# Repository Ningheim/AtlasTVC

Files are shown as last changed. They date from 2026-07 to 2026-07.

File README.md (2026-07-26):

# AtlasTVC
An easily edit-able TVC mount model for any rocketry hobbyist to use on their own rocket. From the clearance between gimbals, to the motor tube outder diameter that you'll be using with this design, everything here is easily adjustable via the variables seen inside the onshape document.

Atlas

Access the onshape document [here](https://cad.onshape.com/documents/687bb891e5fdc86e637405f0/w/7709ffe7004c15a579f76044/e/4d2dc5f323421dbaa3c98495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)
<br>
Printed model available on [Printables](https://www.printables.com/model/1791204-atlastvc)
<br>
*Note: I can't Commit the native CAD source file since the only option is to share via a link*

## Adjustments
Ok as you can see below, the variables control the form factor of the amount so you can adjust it to adhere to whatever you'd like:

<br>
Here's a brief description of each variable so you know exactly what each one represents
#### MotorTubeOD
Outer diameter of the motor tube the mount is built around
#### BaseThickness
This adjusts the thickness of the innermost gimbal, the specific part is called "Base Rig"
#### SecondaryThickness
This adjusts the thickness of the middle gimbal, the specific part is called "Secondary Rig"
#### TertiaryThickness
This adjusts the thickness of the outermost gimbal, the specific part is called "Tertiary Rig"
#### Clearance
Gap between the Base Rig and Secondary Rig axes so they can pivot freely without binding
#### Clearance2
Gap between the Secondary Rig and Tertiary Rig axes so they can pivot freely without binding
#### AxisSize
Diameter of the pivot axis pins connecting each gimbal ring
#### Servo1Offset
Mounting offset for the first servo. The servo head/servo horn needs to be tangent in a way to the cylindrical part it's going to be pushing and pulling on. You'll see reference picture later on in this document.
#### Servo2Offset
Mounting offset for the second servo. The servo head/servo horn needs to be tangent in a way to the cylindrical part it's going to be pushing and pulling on. You'll see reference picture later on in this document.

*NOTE: I have the servo mounts set to fit Miuzei MG90 Servos from the dimensions [here](https://manuals.plus/asin/B0BWJ26PX2). You can redesign the mounts to fit your own but MG90s are often the gold standard for TVC in hobby rocketry*

## Assembly
The [onshape document's](https://cad.onshape.com/documents/687bb891e5fdc86e637405f0/w/7709ffe7004c15a579f76044/e/4d2dc5f323421dbaa3c98495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) assembly tab has the assembly with movable parts and a detailed render to help you mirror it with your own design. You can use this as a type of Demo.
<br>


<br>
First, you align the circular __indentations__ of the innermost gimbal and __holes__ of the secondary gimbal, then you insert the first pair of axis defining rods into the circular opennings to lock the pair in place. Once they're through, glue the circular faces of the axis-defining rods to the __circular indentations__ on the innermost gimbal.

*NOTE: Sand the edges if you need to, all printers have imperfections so if the fit is too tight for you, sand the edges*

Next, you align the circular __indentations__ of the secondary gimbal and __holes__ of the outermost/tertiary gimbal, then you insert the second pair of axis defining rods into the circular opennings to lock the pair in place. Once they're through, glue the circular faces of the axis-defining rods to the __circular indentations__ on the secondary gimbal.

And after that, it's pretty straight forward, you can just slap the servos onto the notches, code them to your needs, and slide in the rocket to get ready to test and launch your TVC system. Make sure the servos are oriented with the wires going out the designated wire holes on each servo mount.

Once you secure the servos onto the model, use servo horns and use a thin firm rod to attach the servo horns and the plastic. Since the rod is going to be linked to the smooth round siding of the cylindrical gimbals, heat the rod up and melt the plastic a little with a soldering iron or something similar. And once it cools down it will form a firm adhesion.

The attachment below is what it should look like fully operational

https://github.com/user-attachments/assets/b01e91cf-8fe1-4efc-a3f6-5ec3da026bce

## Production

Material: Use PETG as it handles the heat from the rocket tube environment than cheaper ones like PLA. It's also less-brittle which can come in handy if the plastic faces stress from servo torque.

Layer height: 0.2mm.

Infill: 30-40%, since this does go into a rocket, under-filling would be detrimental and risks the entire rocket blowing up or someone getting hurt.

Supports: The servo mounts would need some supports as they have a lot of 90 degree drops and sharp corners that require support usage. Everything else is pretty independent of supports since they're mostly just cylinders that are printed straight up.

Orientation: Print the Base Rig, Secondary Rig, and Tertiary Rig flat on their circular faces. Same with all the other cylinders. You will definitely need supports for some of the rigs that have servo mounts on them.

Tolerances: This design was for a standard 0.2mm tolerance. You still might have to sand down some of the parts to ensure they can move past eachother.

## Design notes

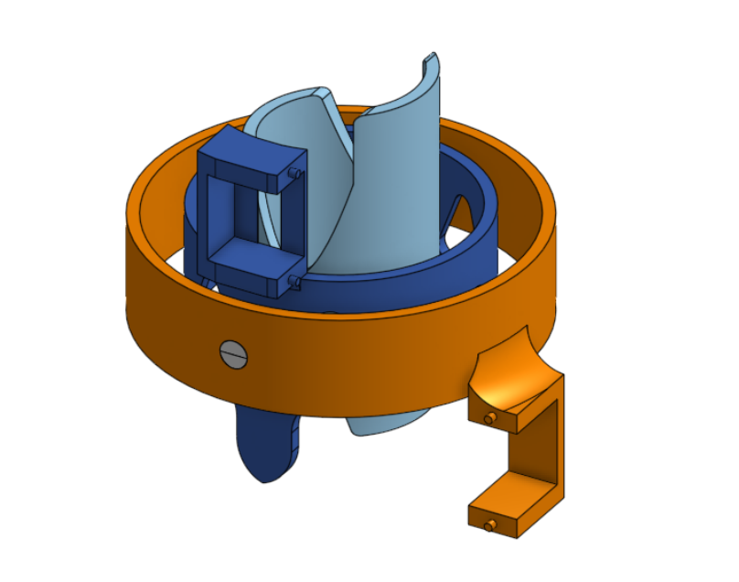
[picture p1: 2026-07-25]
Assets/Atlas.png

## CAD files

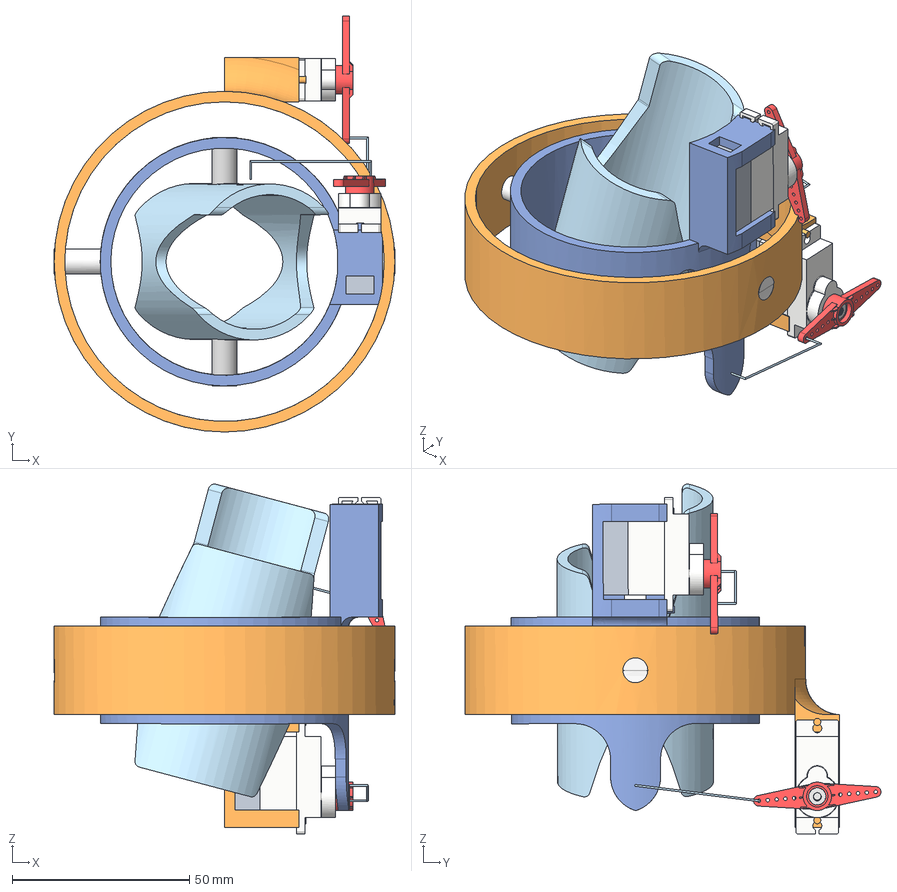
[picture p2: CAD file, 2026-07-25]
CAD/Atlas Assembly.step
96.0 x 117.2 x 98.6 mm
Buttom Part v4:1__Cuerpo2 x 18
Middel Part v7:1__Cuerpo1 x 2
Tertiary Rig
Base Axis 1
Secondary Rig
Base Rig
Base Axis 2
Main Shaft with Gear v3:1__Spur Gear (23 teeth) x 2
Secondary Axis 2
Secondary Axis 1
Upper Part v3:1__Cuerpo1 x 2

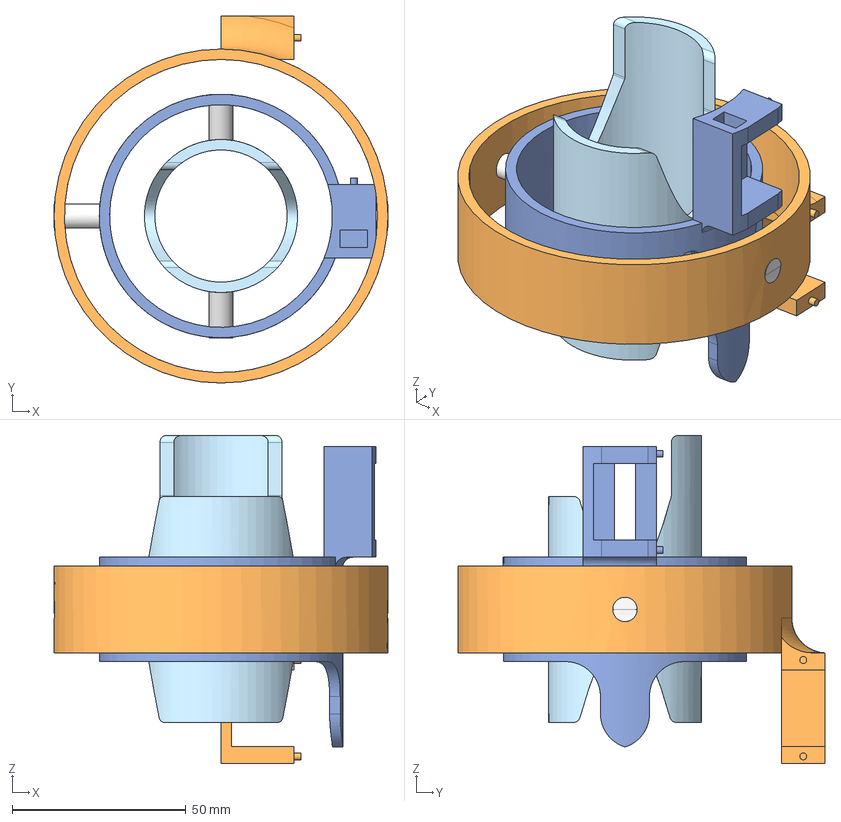
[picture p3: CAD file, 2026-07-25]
CAD/Atlas.step
96.0 x 105.5 x 94.3 mm

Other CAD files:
CAD/Atlas.stl

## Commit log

2026-07-25 CAD Files
    Starting to work on the README as well.
    [Atlas.step, Atlas.stl]
2026-07-25 CAD files and Assets
    [Atlas Assembly.step, Atlas.step, Atlas.stl]
